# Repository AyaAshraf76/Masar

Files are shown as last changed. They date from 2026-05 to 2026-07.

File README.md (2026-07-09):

# Masar — Autonomous Self-Driving Car

Graduation project: a self-driving RC car with lane keeping, lane changing, adaptive cruise control (ACC), and self-parking. Built on a Raspberry Pi 5 + STM32 platform with LiDAR and camera, tested on a custom racetrack with two lanes and a parking area.

## Repo structure

| Folder | What's in it |
|---|---|
| `firmware/` | STM32 motor PID + encoder firmware |
| `trajectory_control/` | Kinematics, pure pursuit, trajectory controller (runs on Pi) |
| `perception/lane_detection/` | ONNX lane detection model + ROS2 lane_bridge + viewer |
| `adaptive_cruise_control/` | LiDAR streaming + ROS2 ACC nodes + motor server |
| `self_parking/` | ROS2 self-parking pipeline (camera, U-Net, YOLO, path planner) |
| `rl_lane_keeping/` | PPO training scripts for lane keeping in simulation (v3 → v3.3) |
| `simulation/` | Unity sim build + gym-donkeycar submodule |
| `car_design/` | Mechanical CAD + PCB files (to be added) |
| `dev_tools/` | Old motor test scripts, kept for reference |

## System overview

The car runs a Raspberry Pi 5 as the main computer and an STM32 for low-level motor control, connected over UART. ROS2 Humble runs on a laptop and handles the heavier processing (ACC, self-parking decisions). Sensor data goes from the Pi to the laptop over TCP, and speed commands come back the same way.

```
Raspberry Pi 5                         Laptop (ROS2)
───────────────                        ─────────────
lane_stream_final.py  ── TCP:9999 ──>  lane_bridge_node    -> /lane_error, /current_lane
                       └─ TCP:9998 ──>  lane_viewer.py

lidar_stream.py       ── TCP:9997 ──>  lidar_bridge_node   -> /scan
                                        acc_node            -> /acc_speed_command, /acc_zone
acc_motor_server.py   <── TCP:9998 ──  acc_tcp_sender_node

trajectory_angle_v11.py
  -> kinematics.py / pure_pursuit.py -> stm32_bridge_uart.py -- UART --> STM32 --> motors
```

## Hardware

- Raspberry Pi 5 — camera inference, trajectory control
- STM32 — motor PWM, encoder feedback, odometry
- Pi Camera — lane detection input (320×240 RGB → ONNX segmentation)
- RPLIDAR A1M8 — obstacle detection for ACC
- 4WD differential drive chassis, two lanes 35cm wide each

## Lane detection

3-class semantic segmentation (background / solid boundary / lane separator) running on the Pi at ~5 FPS. The model outputs pixel-level masks, post-processing extracts lane geometry (center, width, which lane, error in cm, curvature). Two calibration values per lane convert pixel error to real-world centimeters.

## Lane keeping + lane changing

The trajectory controller is a state machine:

- **LANE_KEEPING** — PID on `error_cm` from camera, with confidence-scaled low-pass, innovation clamp, leaky integral for corners, and corner slowdown
- **LANE_CHANGING** — pure pursuit following S-curve waypoints from current pose to adjacent lane
- **STOPPED** — motors off (ACC red zone or manual stop)

## ACC

LiDAR zones: GREEN (full speed), YELLOW (slow), RED (stop). The ACC node filters points to a forward cone, clusters them, and rejects wall-sized returns. Only brakes for obstacles in the car's own lane — if the other lane is clear, it can trigger a lane change instead.

## RL training (simulation)

PPO agent trained in DonkeyCar simulator. Key iterations:

- **v3** — switched to steering-rate actions (policy outputs a delta, not absolute angle) to fix bang-bang behavior. Made reward always ≥ 0 while alive so crashing is never better than staying on track
- **v3.2** — added damping bonus to penalize high lateral speed near the target. Added always-on speed term for the throttle head
- **v3.3** — widened damping window with glide-slope approach. Capped speed during lane changes to reduce entry oscillation

## Getting the code

```bash
git clone --recurse-submodules <repo-url>
# or if already cloned:
git submodule update --init --recursive
```

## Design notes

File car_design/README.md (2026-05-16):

# Car Design

Mechanical CAD and PCB design files for the car.

- `mechanical/` — chassis CAD files
- `pcb/` — PCB design files (KiCad)

Files to be added.

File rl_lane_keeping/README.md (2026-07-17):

# RL Lane Keeping

PPO lane-keeping agent trained in the DonkeyCar simulator (Unity). The car drives on a two-lane oval track (inner lane at CTE = -1.6, outer at CTE = +1.6, walls at ±3.2) and has to track a target that switches lanes every 1500 steps.

Went through six iterations (v1 → v3.3) to get from 30 crashes per 5000 steps to zero crashes with tight tracking.

## Development history

### v1 (baseline) — 500k steps
First attempt. 30 crashes in 5000 steps, all the same pattern: the car corrects with full steering lock, recovers, then holds full lock for 12-15 more steps and sweeps into the opposite wall. 72% of steps were at steering saturation (±1.00). Never reached the left lane at all.

Two problems: (1) no lateral velocity in the observation, so the policy couldn't tell "still drifting" from "already recovered", and (2) raw steering output clips to [-1,+1] which makes a Gaussian policy collapse into bang-bang control.

### v2 — added cte_rate to observation
Added per-step CTE change to the obs. Crashes continued — having the info helped but the bang-bang steering made it impossible to act on it. Necessary but not sufficient.

### v3 — structural fixes (the big one)
Two changes that fixed everything:

1. **Positive reward while alive**: the old reward made crashing rational — sitting in the wrong lane cost ~-2/step forever, crashing cost -5 once. The policy correctly learned to crash. Fix: reward is always ≥ 0 while alive, crash = -10. Now surviving always beats dying.

2. **Steering-rate actions**: instead of outputting a raw angle, the policy outputs a steering *delta* (max ±0.15/step), integrated by the wrapper. Sweeping across the track now takes many deliberate actions instead of one held saturation. Current steering angle added to obs.

Also fixed: cte_rate spike on first step (stale last_cte), cte_rate scaled ×5.

Result: **zero crashes** for the first time. Outer lane median error 0.22. But the inner lane had a ~200-step limit cycle (sweeping ±2.2 through the target), and the throttle head went dead.

### v3.1 — damping bonus
Added `r_damp`: bonus for arriving at the target slowly (low lateral velocity when close). Always-on speed term to wake up the throttle head.

Result: right lane improved to 0.10 median error. But 5 crashes appeared at one specific track location — car held full-left lock drifting into the wall for 14 steps. The damping only fired below error 0.5, and the near-wall reward was too weak to pull it back.

### v3.2 — wall drift arrest
Added a near-wall bonus (when CTE > 2.0) rewarding low lateral velocity regardless of lane error.

Result: **zero crashes** again. Max CTE dropped from 3.26 to 2.43. Left lane mean error down to 1.30, oscillation range contracted to [-2.3, +1.5]. But the limit cycle still survived at reduced amplitude.

### v3.3 — glide-slope damping + lane-change speed cap
Two targeted fixes:

1. Widened damping window to error < 0.9 with allowed lateral speed scaling with distance (allowed = 0.10 + 0.35 × lane_error). Rewards decelerating approach at every distance, not just the last 0.5.

2. Cut throttle to 0 during lane changes when speed > 0.45. The old code let the car enter the new lane at 0.8 speed with lateral rate ~1.2, seeding the oscillation every time.

## Results summary

Eval is a deterministic 5000-step rollout. "Right err" is the median tracking error on the outer lane (+1.6), "Left err" is the mean error on the inner lane (-1.6).

| Version | What changed | Crashes | Right err | Left err | Max CTE |
|---|---|---|---|---|---|
| v1 | baseline | 30 | — | — | >3.2 |
| v2 | + cte_rate obs | ~30 | — | — | >3.2 |
| v3 | rate actions + positive reward | 0 | 0.22 | 1.93 | 2.63 |
| v3.1 | + damping + speed term | 5 | 0.10 | 1.60 | 3.26 |
| v3.2 | + wall drift arrest | 0 | 0.09 | 1.30 | 2.43 |
| v3.3 | + glide-slope + entry cap | 0 | 0.09 | 1.17 | 2.37 |

The biggest jump was v3: replacing the reward (so crashing is never better than surviving) and switching to steering-rate actions (so bang-bang is impossible). Everything after that was reward tuning to tighten tracking.

## Files

- `train_lane_scratch_v3.py` — v3: steering-rate actions + positive reward
- `train_lane_scratch_v3_2.py` — v3.2: damping + always-on speed + wall drift arrest
- `train_lane_scratch_v3_3.py` — v3.3: glide-slope damping + lane-change speed cap
- `ppo_lane_scratch_v3.zip` — trained model weights (place in same dir to resume)
- `measure_cte.py` — logs CTE values while driving in the sim, for checking tracking accuracy

## Running

```bash
# train (resumes from ppo_lane_scratch_v3.zip if present)
python train_lane_scratch_v3_3.py

# measure CTE while manually driving
python measure_cte.py
```

Needs `gymnasium`, `gym_donkeycar`, `stable-baselines3`, `torch`, and the Unity sim binary from `simulation/`.

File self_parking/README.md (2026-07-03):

# Self-Parking

ROS2 node pipeline that lets the car detect a parking slot, decide
whether to enter it, and drive itself in — all on the same racetrack
used for lane keeping/ACC, in the dedicated parking-slot area.

These currently live as plain node scripts (not yet wrapped into a
colcon package like `lane_bridge` / `acc_controller`) — see the
**Packaging** note at the bottom.

## Pipeline / data flow

```
camera_receiver_node ──▶ /camera/image_raw ──┬──▶ unet_node ──▶ /lane_mask, /lane_class
                                              │         │
                                              │         ▼
                                              │   lane_analyzer_node ──▶ /lane_center, /lane_error,
                                              │                          /lane_width, /lane_heading,
                                              │                          /lane_confidence
                                              │
                                              └──▶ yolo_parking_node ──▶ /parking_slot_available,
                                                    parking_slot_node       /parking_slot_center_x/y,
                                                                            /parking_slot_width/height

/lane_error + parking-slot topics ──▶ decision_manager_node ──▶ /parking_state, /parking_target_x

/parking_state, /parking_target_x, /lane_error ──▶ path_planner_node ──▶ /target_steering,
                                                                          /target_speed,
                                                                          /parking_direction

/target_steering, /target_speed, /parking_direction ──▶ wheel_mixer_node ──▶ /wheel_rpm

/wheel_rpm ──▶ tcp_bridge_node ──▶ (TCP) ──▶ Raspberry Pi / STM32 motors
```

## Files

| File | Role |
|---|---|
| `camera_receiver_node.py` | Receives camera frames over TCP/socket and publishes `sensor_msgs/Image` on `/camera/image_raw`. |
| `unet_node.py` | Runs the U-Net segmentation model on each frame, publishes the lane mask and class. |
| `lane_analyzer_node.py` | Turns the segmentation mask into lane center, error, width, heading, and confidence. |
| `yolo_parking_node.py` | YOLO-based detection of the parking slot marker/box. |
| `parking_slot_node.py` | Turns the YOLO detection into slot availability + geometry (`center_x`, `center_y`, `width`, `height`). |
| `decision_manager_node.py` | State machine: decides when to leave lane-following and commit to a parking maneuver, publishes `/parking_state` and `/parking_target_x`. |
| `path_planner_node.py` | Converts the current decision state + lane/slot geometry into steering, speed, and parking-direction commands. |
| `wheel_mixer_node.py` | Mixes steering/speed/direction into individual `/wheel_rpm` targets for all four motors. |
| `tcp_bridge_node.py` | Sends the final `/wheel_rpm` targets over TCP to the Raspberry Pi / STM32 motor firmware. |

## Packaging

For consistency with `perception/lane_detection/ros2_ws` and
`adaptive_cruise_control/ros2_ws`, these nine nodes should eventually
be wrapped into one or two proper `ament_python` ROS2 packages (e.g.
`self_parking_perception` for the camera/U-Net/YOLO/lane-analyzer
nodes and `self_parking_control` for decision-manager/path-planner/
wheel-mixer/tcp-bridge) with their own `package.xml` / `setup.py`. Left
as-is for now since that wasn't part of the requested reorganization —
happy to do that pass next if useful.

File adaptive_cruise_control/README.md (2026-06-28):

# Adaptive Cruise Control (LiDAR)

LiDAR-based ACC system. The Pi streams LiDAR scans to the laptop, ROS2 nodes process them into speed decisions, and the result is sent back to control the motors.

## Files

- `lidar_stream.py` — runs on Pi, reads RPLIDAR A1M8 and streams scans over TCP (port 9997)
- `acc_motor_server.py` — runs on Pi, receives speed commands from laptop via TCP and sends RPM targets to STM32 over UART
- `acc_tcp_sender_node.py` — ROS2 node on laptop, forwards `/acc_speed_command` to the Pi over TCP
- `ros2_ws/src/lidar_bridge/` — ROS2 node that converts the TCP scan stream to `/scan` topic
- `ros2_ws/src/acc_controller/` — ROS2 node that processes `/scan` into speed zones (GREEN/YELLOW/RED)

## How it works

The ACC node filters LiDAR points to a forward cone, clusters them, and keeps only car-sized clusters (rejects the track wall). It uses lane-aware lateral gates so the wall is never mistaken for a car. Publishes `/acc_speed_command` and `/acc_zone`.

## Running

```bash
# Pi terminal 1: LiDAR stream
source ~/lane_env/bin/activate
python3 lidar_stream.py

# Pi terminal 2: motor server (receives speed from laptop, sends to STM32)
python3 acc_motor_server.py

# Laptop terminal 1 — LiDAR bridge:
source /opt/ros/humble/setup.bash && source ~/ros2_ws/install/setup.bash
export ROS_DOMAIN_ID=42
ros2 run lidar_bridge lidar_bridge_node

# Laptop terminal 2 — ACC controller:
source /opt/ros/humble/setup.bash && source ~/ros2_ws/install/setup.bash
export ROS_DOMAIN_ID=42
ros2 run acc_controller acc_node

# Laptop terminal 3 — send speed back to Pi:
source /opt/ros/humble/setup.bash && source ~/ros2_ws/install/setup.bash
export ROS_DOMAIN_ID=42
ros2 run acc_tcp_sender acc_tcp_sender_node

# Monitor:
ros2 topic echo /acc_zone
ros2 topic echo /acc_speed_command
```

For quick tests without building ROS2 packages, `acc_node.py` can run as a standalone script — just source the ROS2 setup so `rclpy` is on the path.

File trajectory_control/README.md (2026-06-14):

# Trajectory Control

High-level trajectory controller running on the Raspberry Pi. Reads lane detection data and ACC commands, computes motor speeds using PID lane keeping or pure pursuit lane changing, and sends them to the STM32 over UART.

## Files

- `trajectory_angle_v11.py` — main controller (state machine: LANE_KEEPING / LANE_CHANGING / STOPPED)
- `kinematics.py` — differential drive forward/inverse kinematics
- `pure_pursuit.py` — pure pursuit path follower for lane changes
- `stm32_bridge_uart.py` — UART interface to the STM32 (send targets, read odometry)

## Running

```bash
python3 trajectory_angle_v11.py
```

Connects to lane_stream_final.py on port 9999 and to the STM32 on `/dev/ttyAMA0`.

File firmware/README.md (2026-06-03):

# STM32 Firmware

PID motor control firmware for the STM32. Handles encoder reading, PID speed control for all 4 wheels, and UART communication with the Raspberry Pi.

## Communication protocol

Receives: `TARGET,rpm1,rpm2,rpm3,rpm4\n`
Sends back: `ODOM,x,y,theta,rpm1,rpm2,rpm3,rpm4\n`

Watchdog timeout: if no TARGET command received for ~200ms, motors stop automatically.

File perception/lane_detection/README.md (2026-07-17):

# Lane Detection and Lane Keeping Perception

Camera-based lane perception for the **MASAR autonomous vehicle**, running on a Raspberry Pi 5 with a Raspberry Pi Camera Module V3.

The subsystem uses a **MobileNetV2-U-Net semantic-segmentation model** exported to ONNX to detect the track markings, estimate the active lane and lane center, calculate lateral error, assign a confidence value, and stream the results to the ROS 2 control stack.

> This module is responsible for perception only. It does not command the motors directly. The trajectory controller consumes its lane measurements and generates the vehicle motion commands.

## System Overview

```mermaid
flowchart LR
    A[Pi Camera V3<br/>640 x 480] --> B[Preprocessing<br/>RGB, resize, normalize]
    B --> C[MobileNetV2-U-Net<br/>ONNX Runtime on Pi 5]
    C --> D[3-Class<br/>Segmentation Mask]
    D --> E[Lane Geometry<br/>Center, width, lane ID, error]
    E --> F[JSON Stream<br/>TCP 9999]
    E --> G[Annotated JPEG Stream<br/>TCP 9998]
    F --> H[ROS 2 lane_bridge]
    H --> I[Lane-Keeping / Trajectory Controller]
    G --> J[Laptop Viewer]
```

### End-to-End Processing Sequence

1. Capture a `640 x 480` frame using Pi Camera V3.
2. Convert the frame to RGB.
3. Resize it to the model input size, `320 x 240`.
4. Normalize pixel values to `[0, 1]` and convert from HWC to CHW format.
5. Run one ONNX inference pass.
6. Apply `argmax` across the model classes to obtain a class-index mask.
7. Process the bottom 80% of the mask as the region of interest.
8. Extract solid-boundary and lane-separator pixels.
9. Estimate the active lane, lane width, and lane center.
10. Calculate signed error in pixels and an approximate lane-aware error in centimeters.
11. Assign a confidence value based on the available visual evidence.
12. Send lane data to the ROS 2 bridge and stream an annotated frame to the viewer.

## Model

### Architecture

- **Task:** Semantic segmentation
- **Encoder:** MobileNetV2 with transfer learning
- **Decoder:** U-Net-style upsampling path
- **Deployment format:** ONNX
- **Runtime:** ONNX Runtime on Raspberry Pi 5 CPU
- **Input:** `1 x 3 x 240 x 320` RGB tensor
- **Output:** Per-class score map converted to a mask using `argmax`

MobileNetV2-U-Net was selected as a practical compromise between pixel-level segmentation quality and the computational limits of real-time Raspberry Pi deployment.

### Segmentation Classes

| Class ID | Class | Meaning |
|---:|---|---|
| `0` | Background | All pixels that are not lane markings |
| `1` | Solid boundary | Solid white track boundary |
| `2` | Lane separator | Dashed separator between the inner and outer lanes |

### Custom Dataset

A project-specific dataset was collected because public road datasets do not match the indoor RC-car environment. The final dataset includes:

- Inner- and outer-lane views
- Straight sections and curves
- Centered and laterally shifted vehicle positions
- Partial line visibility
- Imperfect driving cases
- The real camera mounting height, tilt, lighting, reflections, and track geometry

Images were labeled with **LabelMe** and converted from annotation JSON files into class-index masks for training.

## Lane Geometry and Error Calculation

### Region of Interest

The geometry stage uses the bottom 80% of the predicted mask:

```text
roi_top = int(0.20 * image_height)
ROI = mask[roi_top:image_height, 0:image_width]
```

The upper part of the image contains distant markings that are more affected by perspective and contribute less reliable information for immediate vehicle control.

### Lane Center

When both markings are valid, the lane center is the midpoint between the solid boundary and separator:

```text
lane_center_x = (solid_x + separator_x) / 2
```

When only one marking is visible, the center is reconstructed using lane-aware geometry, remembered lane width, or the learned offset associated with the cleaner visible line.

### Error Convention

```text
image_center_x = image_width / 2
error_px = lane_center_x - image_center_x
```

- `error_px > 0`: the estimated lane center is to the right of the image center.
- `error_px < 0`: the estimated lane center is to the left of the image center.

The pixel error is the primary perception measurement passed to the controller.

### Pixel-to-Centimeter Calibration

The centimeter value is an auxiliary, lane-aware estimate:

```text
error_calibrated_px = error_px - lane_offset_px
error_cm = error_calibrated_px / pixels_per_cm
```

Documented calibration values:

| Constant | Value |
|---|---:|
| Physical lane width | `36.7 cm` |
| Outer-lane zero offset | `-8.5 px` |
| Inner-lane zero offset | `-7.5 px` |
| Outer-lane scale | `2.19 px/cm` |
| Inner-lane scale | `2.51 px/cm` |

The centimeter estimate is most reliable on straight sections. In curves, perspective and vehicle-heading error affect the image measurement, so `error_cm` should be treated as approximate.

## Confidence Logic

| Visual evidence | Estimation method | Confidence |
|---|---|---:|
| Solid boundary and separator visible | Midpoint of both markings | `1.0` |
| Solid boundary only | Single-line reconstruction | `0.5` |
| Separator only | Single-line reconstruction | `0.4` |
| No marking, previous center available | Low-confidence fallback | `0.2` |
| No usable estimate | Image-center fallback | `0.0` |

Confidence allows the controller to reduce trust in ambiguous measurements instead of treating every frame as equally reliable.

## Output Data

The lane stream sends JSON data through TCP port `9999`. The exact payload can evolve with the runtime script, but the principal fields are:

| Field | Description |
|---|---|
| `lane` | Current lane: `inner`, `outer`, or `unknown` |
| `center` | Estimated lane center in model-image coordinates |
| `error` | Signed lateral error in pixels |
| `error_cm` | Approximate calibrated lateral error in centimeters |
| `confidence` | Reliability of the current estimate |
| `width` | Remembered lane width in pixels |
| `curvature` | Diagnostic separator-slope/curvature estimate |
| `solid_count` / `sep_count` | Number of detected pixels for each lane class |
| `solid_x` / `sep_x` | Representative positions of the detected markings |

The ROS 2 bridge converts the TCP data into lane topics used by the trajectory controller. Confirm the final topic names from `ros2_ws/src/lane_bridge/`.

## Runtime Communication

| Port | Data | Consumer |
|---:|---|---|
| `9999` | JSON lane geometry and diagnostics | ROS 2 bridge / trajectory controller |
| `9998` | Annotated JPEG frames | Laptop viewer |

Only one model inference is performed per camera frame. The same inference result is reused for the JSON output and visual stream to reduce Raspberry Pi CPU load.

## Files

- `lane_model.onnx` and `lane_model_onnx.data` - trained three-class segmentation model
- `lane_stream_final.py` - Pi camera capture, ONNX inference, geometry extraction, JSON server, and annotated-video server
- `lane_viewer.py` - laptop viewer for the annotated JPEG stream (`Q` to quit, `F` for fullscreen)
- `ros2_ws/src/lane_bridge/` - ROS 2 bridge from the Pi JSON stream to lane topics
- `Lane_Detection_Lane_Keeping_Chapter__3_.docx` - complete lane-detection and lane-keeping documentation
- `Lane_Detection_Challenges_Report.docx` - development challenges, diagnoses, and mitigation history

## Engineering Challenges and Final Mitigations

The largest errors occurred in curves, where perspective distortion, partial visibility, and segmentation ambiguity affected the geometric post-processing.

| Challenge | Root cause | Mitigation |
|---|---|---|
| Wrong solid-only fallback direction | The same `-lane_width/2` sign was used for both lanes | Use lane-aware signs for inner and outer lanes |
| Corner bias from full-ROI averaging | Far-ahead curved pixels shifted the arithmetic mean | Use a near-car median from the lowest valid rows |
| Two-wall contamination | Both solid walls could be classified as one class when the separator disappeared | Select the cluster nearest the previous trusted anchor |
| Large separator blob in the inner lane | The curved separator could be over-segmented into a wide region | Learn line-to-center offsets from clean frames and prefer the cleaner line |
| Polynomial-fit overshoot | A straight fit extrapolated below the available curved pixels | Avoid extrapolation; estimate only from observed near-car pixels |
| Anchor snowballing | A bad frame could corrupt the next frame's filter anchor | Save anchors before update and hard-update only from clean frames |
| Frozen output during contaminated frames | Holding the last clean result made the measurement unresponsive | Keep a live output and limit only the maximum per-frame jump |

These measures reduced isolated spikes and improved robustness, but they did not completely eliminate systematic curve error.

## Known Limitations

- Curves remain less accurate than straight sections because the separator may become a wide curved blob or leave the field of view.
- The system relies on one forward-facing camera, so single-line fallback is sometimes unavoidable.
- The observed processing rate is approximately `5-6 FPS`; at vehicle speed, this introduces measurable perception delay.
- The camera position and tilt must remain fixed after training and calibration.
- Strong glare and reflections from the indoor track can affect segmentation.
- The trained model is specialized for the project track and lighting distribution.
- The centimeter error is an approximate interpretation, not a complete ground-plane localization estimate.

## Future Improvements

- Add inverse perspective mapping / bird's-eye-view calibration.
- Apply camera undistortion using measured camera calibration parameters.
- Retrain with additional inner-lane corner, glare, blur, and partial-visibility examples.
- Replace single-position extraction with row-wise or polynomial lane modeling that does not extrapolate beyond observed pixels.
- Fuse camera measurements with wheel odometry or IMU data using a state estimator such as an Extended Kalman Filter.
- Increase inference frame rate through model optimization or hardware acceleration.
- Add physical-plausibility checks for impossible changes in lane width or error.

## Deploying the Model to the Raspberry Pi

Replace `<PI_IP>` with the current Raspberry Pi address.

```bash
scp lane_model.onnx pi@<PI_IP>:/home/pi/
scp lane_model_onnx.data pi@<PI_IP>:/home/pi/
```

Install the required runtime packages inside the environment used by the lane script:

```bash
pip install --upgrade onnxruntime numpy
```

### Verify That the Model Loads

```bash
python3 - <<'PY'
import numpy as np
import onnxruntime as ort

session = ort.InferenceSession(
    "/home/pi/lane_model.onnx",
    providers=["CPUExecutionProvider"],
)
input_name = session.get_inputs()[0].name
dummy = np.random.rand(1, 3, 240, 320).astype(np.float32)
output = session.run(None, {input_name: dummy})
print("Output shape:", output[0].shape)
print("Model loaded successfully")
PY
```

### Benchmark Inference

```bash
python3 - <<'PY'
import time
import numpy as np
import onnxruntime as ort

session = ort.InferenceSession(
    "/home/pi/lane_model.onnx",
    providers=["CPUExecutionProvider"],
)
input_name = session.get_inputs()[0].name
dummy = np.random.rand(1, 3, 240, 320).astype(np.float32)

for _ in range(5):
    session.run(None, {input_name: dummy})

samples = []
for _ in range(30):
    start = time.perf_counter()
    session.run(None, {input_name: dummy})
    samples.append(time.perf_counter() - start)

mean_time = float(np.mean(samples))
print(f"Mean inference: {mean_time * 1000:.1f} ms")
print(f"Inference FPS: {1.0 / mean_time:.1f}")
PY
```

## Running the Subsystem

### Raspberry Pi

```bash
source ~/lane_env/bin/activate
python3 lane_stream_final.py
```

### Laptop Viewer

```bash
python3 lane_viewer.py
```

### ROS 2 Bridge

```bash
source /opt/ros/humble/setup.bash
source ~/ros2_ws/install/setup.bash
ros2 run lane_bridge lane_bridge_node
```

## Documentation

For the full training methodology, equations, calibration, validation, curve analysis, and development history, see:

- `Lane_Detection_Lane_Keeping_Chapter__3_.docx`
- `Lane_Detection_Challenges_Report.docx`

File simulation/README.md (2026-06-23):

# Simulation

Unity-based simulation environment for training and testing.

- `unity_build/` — built simulator binary (worked_version.x86_64)
- `gym-donkeycar/` — OpenAI Gym wrapper (git submodule)

The RL training scripts in `rl_lane_keeping/` connect to this simulator.

```bash
# make sure submodule is initialized
git submodule update --init --recursive
```

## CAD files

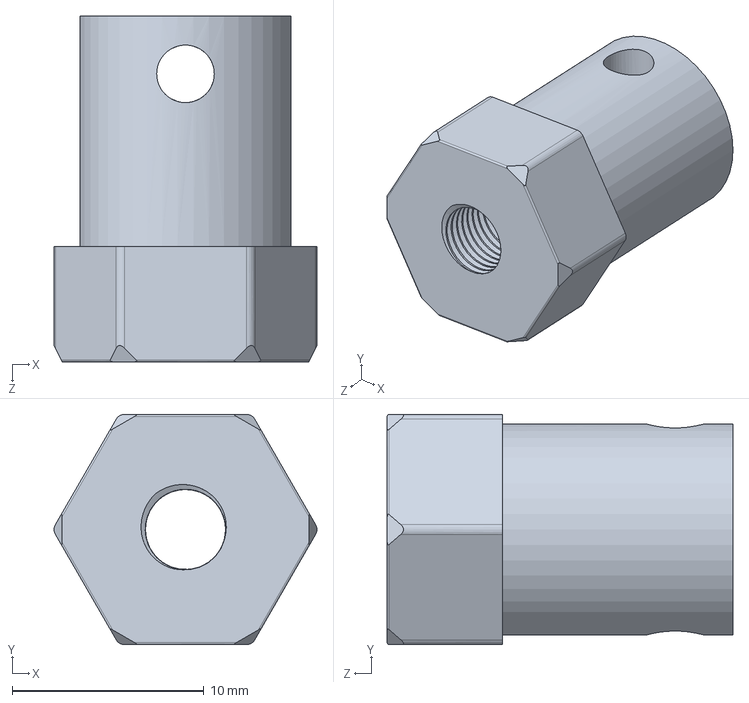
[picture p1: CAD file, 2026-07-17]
car_design/mechanical/motor_adapter.SLDPRT
13.7 x 12.0 x 18.0 mm

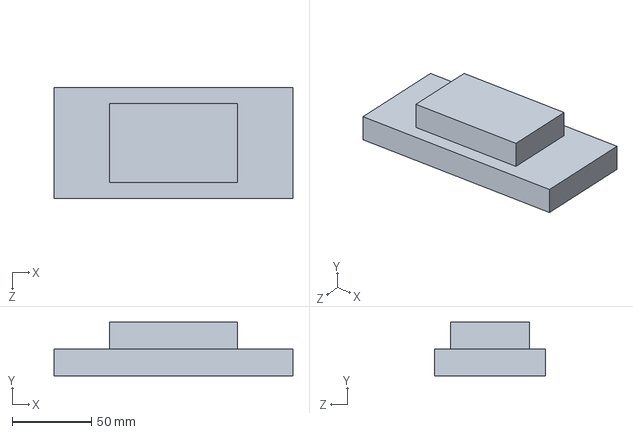
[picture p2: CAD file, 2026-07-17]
car_design/mechanical/POWERBANK.SLDPRT
151.0 x 34.0 x 70.0 mm

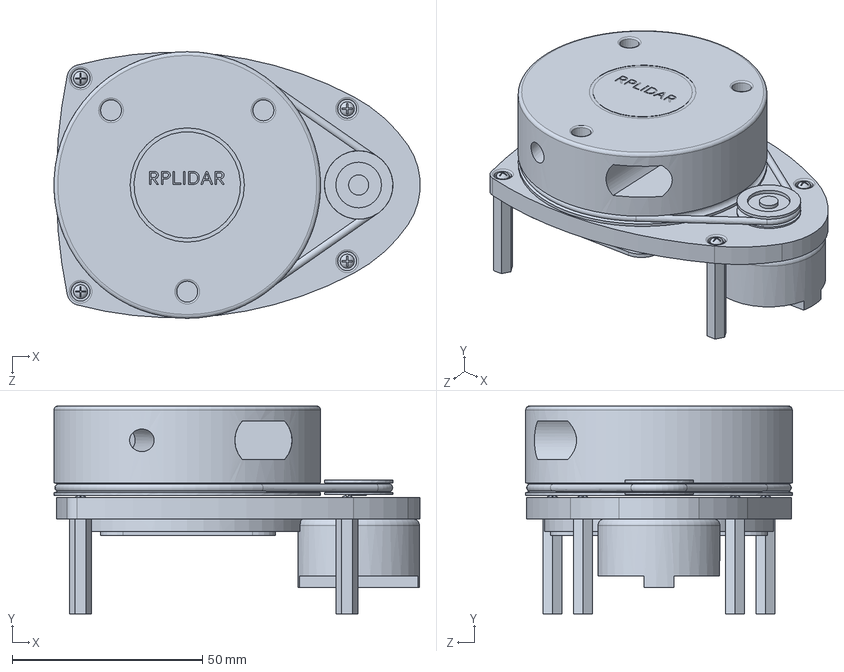
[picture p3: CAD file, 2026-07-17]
car_design/mechanical/RPLidar_SCTL.SLDPRT
96.1 x 54.6 x 70.0 mm

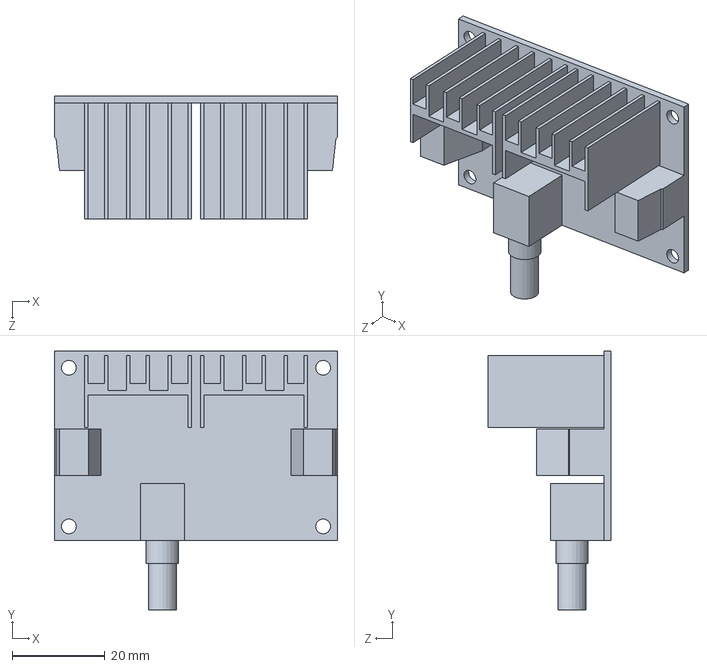
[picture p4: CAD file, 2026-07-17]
car_design/mechanical/xl4016.SLDPRT
61.0 x 55.8 x 26.6 mm

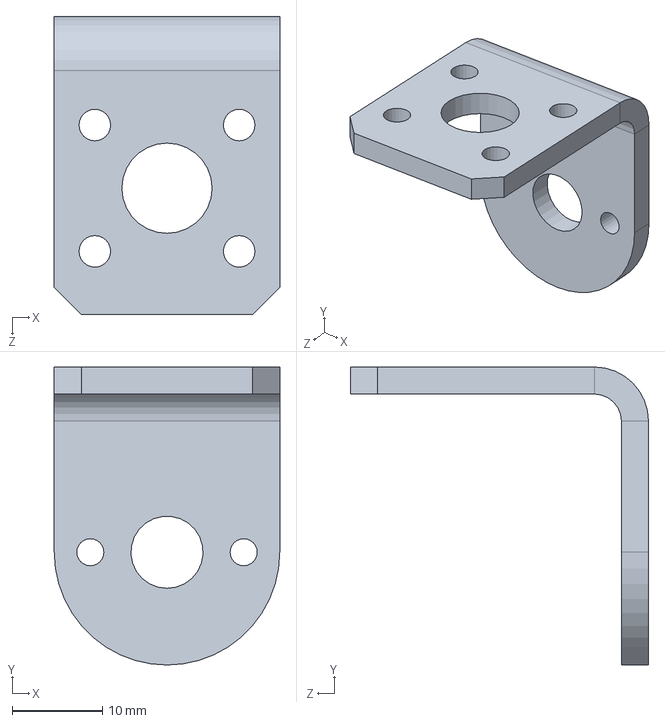
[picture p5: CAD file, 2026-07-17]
car_design/mechanical/DC motor Mount.SLDPRT
25.0 x 33.0 x 33.0 mm

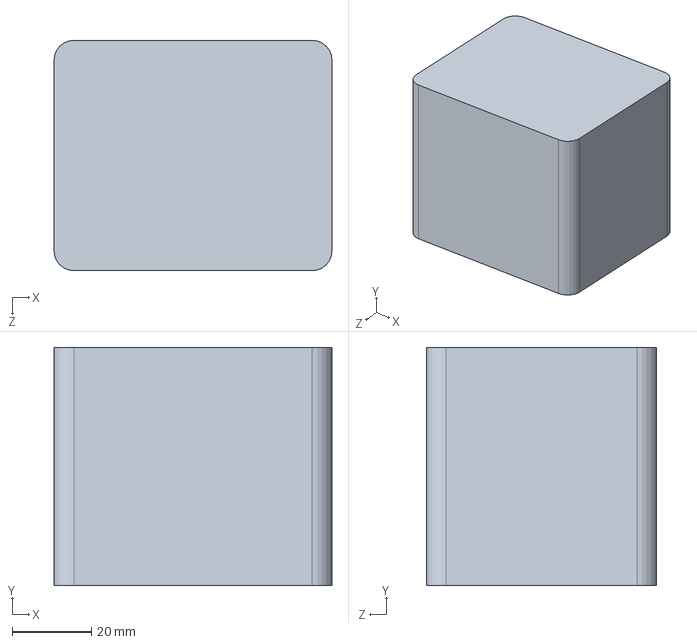
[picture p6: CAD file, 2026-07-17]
car_design/mechanical/battery.SLDPRT
70.0 x 60.0 x 58.0 mm

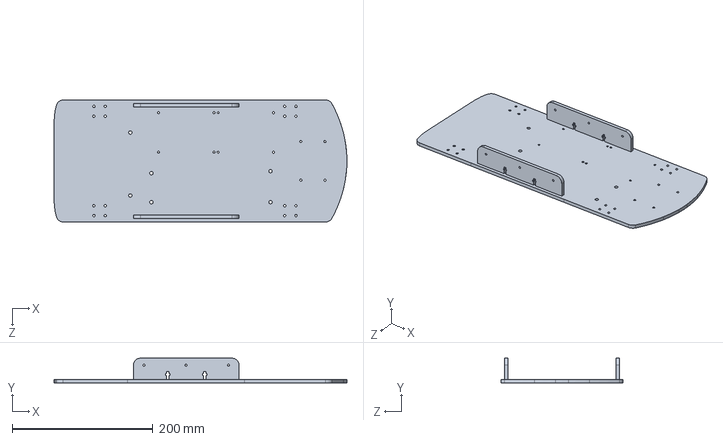
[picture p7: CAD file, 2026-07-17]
car_design/mechanical/chasiss.SLDPRT
415.6 x 35.0 x 173.0 mm

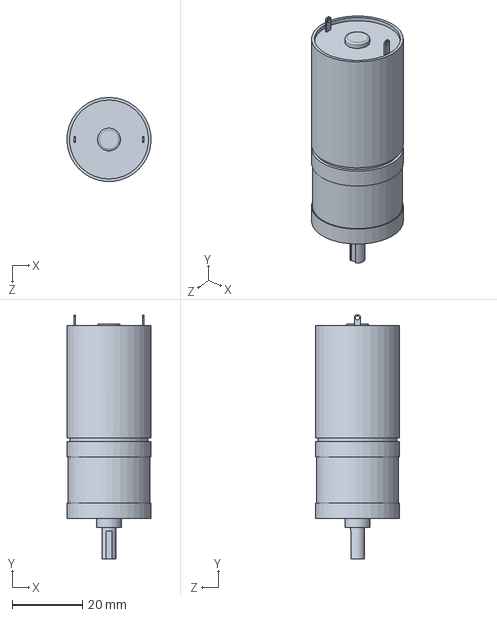
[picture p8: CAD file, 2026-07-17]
car_design/mechanical/DC-Motor.SLDPRT
24.0 x 69.5 x 24.0 mm

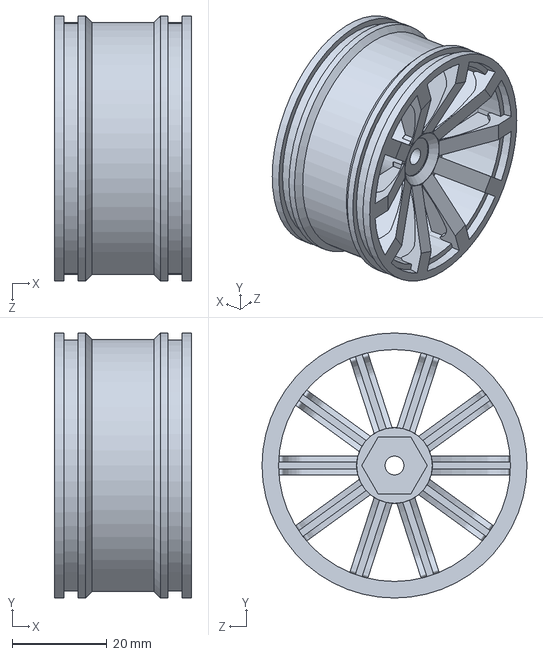
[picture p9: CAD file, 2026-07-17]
car_design/mechanical/blue_wheel_frame.SLDPRT
29.0 x 56.0 x 56.0 mm

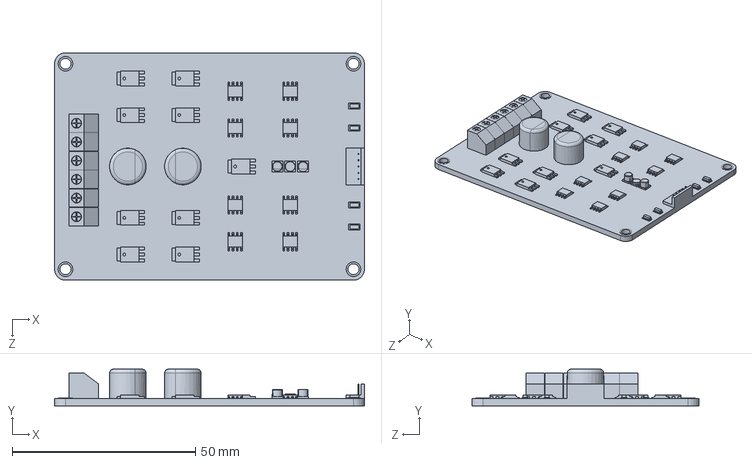
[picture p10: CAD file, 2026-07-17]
car_design/mechanical/Motor Driver.SLDPRT
84.5 x 10.0 x 62.0 mm

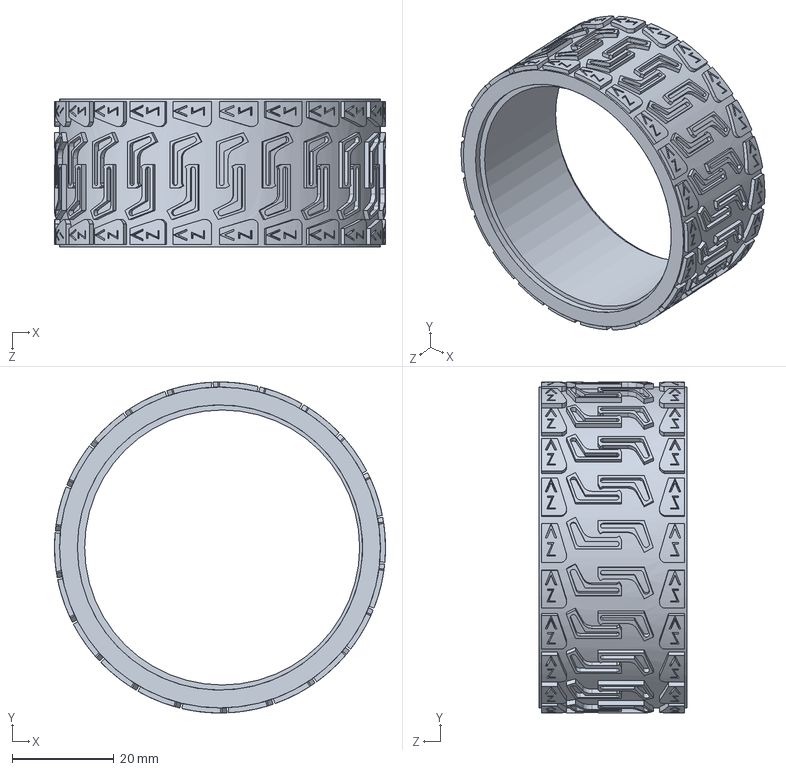
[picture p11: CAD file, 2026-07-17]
car_design/mechanical/65mm tire.SLDPRT
65.0 x 65.0 x 29.0 mm

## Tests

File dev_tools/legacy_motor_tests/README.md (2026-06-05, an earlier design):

# Legacy Motor Test Scripts

Early prototype firmware/scripts used while bringing up the drivetrain,
**before** the final PID+odometry firmware. Superseded by
`firmware/stm32_pid_uart/pid_realtime_uart.ino` +
`trajectory_control/stm32_bridge_uart.py`. Kept here for history only
— pin mappings in these files do **not** match the final control PCB.

| Folder | Purpose |
|---|---|
| `modes_feedback_motors/` | STM32 firmware (`modes_feedback_motors.ino`) + Pi-side script (`modes_pi.py`) for an interactive mode-select UART test: 4-wheel speed control vs. steering+speed control, with encoder feedback. Different pin mapping than the final firmware. |
| `motors_keyboard/` | Earliest open-loop test: STM32 firmware (`motors_keyboard.ino`, PWM/DIR only, no encoders/PID) driven from the Pi by raw keyboard input (`keyboard_motor.py`). |

If you don't need this history for the thesis appendix, this whole
folder can be deleted without affecting anything else in the repo.

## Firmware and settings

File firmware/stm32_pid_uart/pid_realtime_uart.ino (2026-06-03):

//////////////////// MOTOR 1 ////////////////////
#define ENCA1 PB3
#define ENCB1 PA15
#define PWM1  PA3
#define DIR1  PA2

//////////////////// MOTOR 2 ////////////////////
#define ENCA2 PB10
#define ENCB2 PB11
#define PWM2  PA1
#define DIR2  PA0

//////////////////// MOTOR 3 ////////////////////
#define ENCA3 PA4
#define ENCB3 PA5
#define PWM3  PA10
#define DIR3  PA9

//////////////////// MOTOR 4 ////////////////////
#define ENCA4 PB8
#define ENCB4 PB9
#define PWM4  PA8
#define DIR4  PB15

//////////////////////////////////////////////////
// UART2 to Raspberry Pi (PB6=TX, PB7=RX)
// Serial  = USB debug to laptop
// Serial2 = UART to Pi
//////////////////////////////////////////////////
HardwareSerial Serial2(PB7, PB6);

volatile long posi1=0, posi2=0, posi3=0, posi4=0;
volatile int  lastEncoded1=0, lastEncoded2=0;
volatile int  lastEncoded3=0, lastEncoded4=0;

float eintegral1=0, eintegral2=0, eintegral3=0, eintegral4=0;

float PPR          = 1980;
float WHEEL_RADIUS = 0.03367;  // update after calibration
float TRACK_WIDTH  = 0.74761;    // update after calibration

float target1=0, target2=0, target3=0, target4=0;

float kp1=4.0, ki1=0.5, kff1=2.4;
float kp2=4.0, ki2=0.5, kff2=2.4;
float kp3=4.0, ki3=0.5, kff3=2.4;
float kp4=4.0, ki4=0.5, kff4=2.4;
const float ICLAMP = 40.0;

// Odometry
float odom_x=0, odom_y=0, odom_theta=0;
long prevOdom1=0, prevOdom2=0, prevOdom3=0, prevOdom4=0;

// Watchdog: stop motors if Pi goes silent
unsigned long lastTargetMs = 0;
const unsigned long TIMEOUT_MS = 500;
bool rtActive = false;

// RPM state
static float _rpm1=0, _rpm2=0, _rpm3=0, _rpm4=0;
static long  _prevP1=0, _prevP2=0, _prevP3=0, _prevP4=0;

void setup() {
  Serial.begin(115200);    // USB debug -- connect to laptop to monitor
  Serial2.begin(115200);   // UART to Pi on PB6/PB7

  pinMode(ENCA1,INPUT_PULLUP); pinMode(ENCB1,INPUT_PULLUP);
  pinMode(ENCA2,INPUT_PULLUP); pinMode(ENCB2,INPUT_PULLUP);
  pinMode(ENCA3,INPUT_PULLUP); pinMode(ENCB3,INPUT_PULLUP);
  pinMode(ENCA4,INPUT_PULLUP); pinMode(ENCB4,INPUT_PULLUP);

  attachInterrupt(digitalPinToInterrupt(ENCA1),readEncoder1,CHANGE);
  attachInterrupt(digitalPinToInterrupt(ENCB1),readEncoder1,CHANGE);
  attachInterrupt(digitalPinToInterrupt(ENCA2),readEncoder2,CHANGE);
  attachInterrupt(digitalPinToInterrupt(ENCB2),readEncoder2,CHANGE);
  attachInterrupt(digitalPinToInterrupt(ENCA3),readEncoder3,CHANGE);
  attachInterrupt(digitalPinToInterrupt(ENCB3),readEncoder3,CHANGE);
  attachInterrupt(digitalPinToInterrupt(ENCA4),readEncoder4,CHANGE);
  attachInterrupt(digitalPinToInterrupt(ENCB4),readEncoder4,CHANGE);

  pinMode(PWM1,OUTPUT); pinMode(DIR1,OUTPUT);
  pinMode(PWM2,OUTPUT); pinMode(DIR2,OUTPUT);
  pinMode(PWM3,OUTPUT); pinMode(DIR3,OUTPUT);
  pinMode(PWM4,OUTPUT); pinMode(DIR4,OUTPUT);

  Serial.println("READY - debug on USB, Pi on Serial2 PB6/PB7");
  Serial2.println("READY");
}

void loop() {
  // Read commands from Pi on Serial2
  static char buf[64];
  static uint8_t blen = 0;

  while (Serial2.available()) {
    char c = Serial2.read();
    if (c == '\n') {
      buf[blen] = '\0';
      if (strncmp(buf, "TARGET,", 7) == 0) {
        parseTarget(buf);
      } else if (blen == 1 && buf[0] == 'r') {
        resetOdom();
      }
      blen = 0;
    } else if (c != '\r' && blen < 63) {
      buf[blen++] = c;
    }
  }

  static unsigned long lastTime = 0;
  if (millis() - lastTime < 20) return;
  lastTime = millis();
  float dt = 0.02;

  // Watchdog: Pi went silent -> stop motors
  if (rtActive && (millis() - lastTargetMs) > TIMEOUT_MS) {
    target1=target2=target3=target4=0;
    eintegral1=eintegral2=eintegral3=eintegral4=0;
    rtActive = false;
    Serial.println("WATCHDOG: Pi silent, motors stopped");
  }

  // Odometry update
  long s1,s2,s3,s4;
  noInterrupts(); s1=posi1;s2=posi2;s3=posi3;s4=posi4; interrupts();
  float tpm = PPR / (2.0*PI*WHEEL_RADIUS);
  // Physical test confirmed: M2/M3 are the RIGHT side, M1/M4 are the LEFT side
  // despite their pin names -- swap dL/dR accordingly
  float dL = ((s1-prevOdom1 + s4-prevOdom4)/2.0) / tpm;  // M1,M4 = physical LEFT
  float dR = ((s2-prevOdom2 + s3-prevOdom3)/2.0) / tpm;  // M2,M3 = physical RIGHT
  prevOdom1=s1; prevOdom2=s2; prevOdom3=s3; prevOdom4=s4;
  float dc   = (dL+dR)/2.0;
  // Negated: physically turning right increases theta in our setup
  float dth  = -((dR-dL)/TRACK_WIDTH);
  float tmid = odom_theta + dth/2.0;
  odom_x     += dc*cos(tmid);
  odom_y     += dc*sin(tmid);
  odom_theta += dth;
  odom_theta  = atan2(sin(odom_theta),cos(odom_theta));

  // PID
  runPID(dt);

  // Send odometry to Pi on Serial2
  // Format: ODOM,x,y,theta,rpm1,rpm2,rpm3,rpm4
  Serial2.print(F("ODOM,"));
  Serial2.print(odom_x,4);    Serial2.print(',');
  Serial2.print(odom_y,4);    Serial2.print(',');
  Serial2.print(odom_theta,5);Serial2.print(',');
  Serial2.print(_rpm1,2);     Serial2.print(',');
  Serial2.print(_rpm2,2);     Serial2.print(',');
  Serial2.print(_rpm3,2);     Serial2.print(',');
  Serial2.println(_rpm4,2);

  // Mirror odometry to USB debug port so you can monitor on laptop too
  Serial.print(F("ODOM,"));
  Serial.print(odom_x,4);    Serial.print(',');
  Serial.print(odom_y,4);    Serial.print(',');
  Serial.print(odom_theta*180.0/PI,2); Serial.print(F("deg | RPM "));
  Serial.print(_rpm1,1); Serial.print(' ');
  Serial.print(_rpm2,1); Serial.print(' ');
  Serial.print(_rpm3,1); Serial.print(' ');
  Serial.println(_rpm4,1);
}

void parseTarget(char* line) {
  char tmp[64]; strncpy(tmp,line,63); tmp[63]='\0';
  strtok(tmp,",");
  char* t1=strtok(NULL,","); if(!t1) return;
  char* t2=strtok(NULL,","); if(!t2) return;
  char* t3=strtok(NULL,","); if(!t3) return;
  char* t4=strtok(NULL,","); if(!t4) return;
  target1=atof(t1); target2=atof(t2);
  target3=atof(t3); target4=atof(t4);
  lastTargetMs=millis();
  rtActive=true;
}

void resetOdom() {
  odom_x=odom_y=odom_theta=0;
  noInterrupts();
  prevOdom1=posi1; prevOdom2=posi2;
  prevOdom3=posi3; prevOdom4=posi4;
  interrupts();
  Serial2.println(F("ODOM RESET"));
  Serial.println(F("Odometry reset"));
}

void runPID(float dt) {
  auto calcRPM = [&](volatile long& posi, long& prev, float& filt) {
    long snap; noInterrupts(); snap=posi; interrupts();
    float raw = ((snap-prev)/PPR)*(60.0/dt);
    prev = snap;
    filt = 0.8*filt + 0.2*raw;
  };
  calcRPM(posi1,_prevP1,_rpm1);
  calcRPM(posi2,_prevP2,_rpm2);
  calcRPM(posi3,_prevP3,_rpm3);
  calcRPM(posi4,_prevP4,_rpm4);

  auto pidStep = [&](float tgt, float rpm, float& eint,
                     float kp, float ki, float kff,
                     int pwm, int dir) {
    float u = kff*tgt + kp*(tgt-rpm) + ki*eint;
    float pwr = fabs(u); if(pwr>255) pwr=255;
    if(fabs(tgt-rpm)>15) pwr=max(pwr,150.0f);
    setMotor(pwm, dir, (u>=0)?1:-1, pwr);
    if(pwr<255){ eint+=(tgt-rpm)*dt; eint=constrain(eint,-ICLAMP,ICLAMP); }
  };

  pidStep(target1,_rpm1,eintegral1,kp1,ki1,kff1,PWM1,DIR1);
  pidStep(target2,_rpm2,eintegral2,kp2,ki2,kff2,PWM2,DIR2);
  pidStep(target3,_rpm3,eintegral3,kp3,ki3,kff3,PWM3,DIR3);
  pidStep(target4,_rpm4,eintegral4,kp4,ki4,kff4,PWM4,DIR4);
}

void setMotor(int pwmPin, int dirPin, int dir, float pwmVal) {
  analogWrite(pwmPin, (int)pwmVal);
  digitalWrite(dirPin, dir==1 ? HIGH : LOW);
}

#define ENC_ISR(N,A,B,pos,last) \
void readEncoder##N() { \
  int e=(digitalRead(A)<<1)|digitalRead(B); \
  int s=(last<<2)|e; \
  if(s==0b1101||s==0b0100||s==0b0010||s==0b1011) pos++; \
  if(s==0b1110||s==0b0111||s==0b0001||s==0b1000) pos--; \
  last=e; \
}

ENC_ISR(1,ENCA1,ENCB1,posi1,lastEncoded1)
ENC_ISR(2,ENCA2,ENCB2,posi2,lastEncoded2)
ENC_ISR(3,ENCA3,ENCB3,posi3,lastEncoded3)
ENC_ISR(4,ENCA4,ENCB4,posi4,lastEncoded4)

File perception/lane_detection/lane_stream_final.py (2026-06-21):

#!/usr/bin/env python3
"""
Lane Detection - Combined Final Script
Runs on Raspberry Pi 5

Does TWO things simultaneously from ONE inference:
  1. Sends JSON data  ^f^r port 9999  ^f^r ROS2 bridge on laptop
  2. Sends visual stream  ^f^r port 9998  ^f^r viewer on laptop

error_cm is a pure post-calculation added on top of the
existing lane-aware pixel error. Lane detection logic,
ROI, voting, and smoothing are UNCHANGED.

Both lanes are 35cm wide in reality (confirmed).
"""

import cv2
import numpy as np
import onnxruntime as ort
import socket
import struct
import time
import json
import threading
from picamera2 import Picamera2
from libcamera import controls
from collections import deque, Counter


#  ^t^` ^t^` Configuration  ^t^` ^t^` ^t^` ^t^` ^t^` ^t^` ^t^` ^t^` ^t^` ^t^` ^t^` ^t^` ^t^` ^t^` ^t^` ^t^` ^t^` ^t^` ^t^` ^t^` ^t^` ^t^` ^t^` ^t^` ^t^` ^t^` ^t^` ^t>
MODEL_PATH    = '/home/pi/lane_model.onnx'
JSON_PORT     = 9999   # ROS2 bridge connects here
VIDEO_PORT    = 9998   # viewer on laptop connects here
INPUT_W       = 320
INPUT_H       = 240
ALPHA         = 0.3
SOLID_ALPHA   = 0.4
SEP_THRESHOLD = 110.0
LANE_HISTORY  = 10
MIN_VOTES     = 6

#  ^t^` ^t^` Real-world lane width (confirmed by measurement)  ^t^` ^t^` ^t^` ^t^` ^t^` ^t^` ^t^`
LANE_WIDTH_CM = 36.7

#  ^t^` ^t^` CM calibration (PLACEHOLDERS until you run the test)  ^t^` ^t^` ^t^`
# Run Test A (outer) and Test B (inner) below, then fill in
# real numbers here. Until then error_cm == error in px
# (offset 0, scale 1)  ^`^t completely harmless default.
ERROR_OFFSET_OUTER_PX = -8.5
ERROR_OFFSET_INNER_PX = -7.5
PIXELS_PER_CM_OUTER    = 2.19
PIXELS_PER_CM_INNER    = 2.51




#  ^t^` ^t^` Colors  ^t^` ^t^` ^t^` ^t^` ^t^` ^t^` ^t^` ^t^` ^t^` ^t^` ^t^` ^t^` ^t^` ^t^` ^t^` ^t^` ^t^` ^t^` ^t^` ^t^` ^t^` ^t^` ^t^` ^t^` ^t^` ^t^` ^t^` ^t^` ^t^`>
COLOR_WHITE = (255, 255, 255)
COLOR_GREEN = (0, 255, 0)
COLOR_CYAN  = (0, 255, 255)
COLOR_BLUE  = (255, 0, 0)
COLOR_BLACK = (0, 0, 0)

mask_colors = np.array([
    [50,  50,  50],
    [0,   255, 0 ],
    [0,   255, 255],
], dtype=np.uint8)


#  ^t^` ^t^` Load model  ^t^` ^t^` ^t^` ^t^` ^t^` ^t^` ^t^` ^t^` ^t^` ^t^` ^t^` ^t^` ^t^` ^t^` ^t^` ^t^` ^t^` ^t^` ^t^` ^t^` ^t^` ^t^` ^t^` ^t^` ^t^` ^t^` ^t^` ^t^` >
print('Loading model...')
sess_options = ort.SessionOptions()
sess_options.intra_op_num_threads = 4
sess_options.inter_op_num_threads = 4


sess = ort.InferenceSession(
    MODEL_PATH,
    sess_options=sess_options,
    providers=['CPUExecutionProvider'])

input_name = sess.get_inputs()[0].name
print(f'Model loaded: {input_name}')


#  ^t^` ^t^` State  ^t^` ^t^` ^t^` ^t^` ^t^` ^t^` ^t^` ^t^` ^t^` ^t^` ^t^` ^t^` ^t^` ^t^` ^t^` ^t^` ^t^` ^t^` ^t^` ^t^` ^t^` ^t^` ^t^` ^t^` ^t^` ^t^` ^t^` ^t^` ^t^` >
prev_center    = None
prev_solid_pos = None
prev_sep_pos   = None
lane_history   = deque(maxlen=LANE_HISTORY)
width_history  = deque(maxlen=50)
current_lane   = 'unknown'

#  ^t^` ^t^` Calibration test buffer (terminal-only, no effect on
#    streaming)  ^t^` ^t^` ^t^` ^t^` ^t^` ^t^` ^t^` ^t^` ^t^` ^t^` ^t^` ^t^` ^t^` ^t^` ^t^` ^t^` ^t^` ^t^` ^t^` ^t^` ^t^` ^t^` ^t^` ^t^` ^t^` ^t^` ^t^` ^t^` ^t^` ^t^>
calib_buffer = deque(maxlen=15)


#  ^t^` ^t^` Preprocess  ^t^` ^t^` ^t^` ^t^` ^t^` ^t^` ^t^` ^t^` ^t^` ^t^` ^t^` ^t^` ^t^` ^t^` ^t^` ^t^` ^t^` ^t^` ^t^` ^t^` ^t^` ^t^` ^t^` ^t^` ^t^` ^t^` ^t^` ^t^` >
def preprocess(frame_bgr):
    frame_rgb = cv2.cvtColor(
        frame_bgr, cv2.COLOR_BGR2RGB)
    inp = cv2.resize(
        frame_rgb, (INPUT_W, INPUT_H),
        interpolation=cv2.INTER_LINEAR)
    inp = inp.astype(np.float32) / 255.0
    inp = inp.transpose(2, 0, 1)[np.newaxis]
    return inp

#  ^t^` ^t^` Geometry  ^t^` ^t^` ^t^` ^t^` ^t^` ^t^` ^t^` ^t^` ^t^` ^t^` ^t^` ^t^` ^t^` ^t^` ^t^` ^t^` ^t^` ^t^` ^t^` ^t^` ^t^` ^t^` ^t^` ^t^` ^t^` ^t^` ^t^` ^t^` ^t>
def extract_geometry(mask):
    global prev_center, prev_solid_pos
    global prev_sep_pos, current_lane

    h, w   = mask.shape
    img_cx = w / 2.0

    roi_top = int(h * 0.20)
    roi     = mask[roi_top:, :]

    solid_cols = np.where(roi == 1)[1]
    sep_cols   = np.where(roi == 2)[1]

    solid_count = len(solid_cols)
    sep_count   = len(sep_cols)

    # Track actual detection this frame
    actually_has_sep   = sep_count   > 8
    actually_has_solid = solid_count > 8

    sep_x   = float(np.mean(sep_cols)) \
               if actually_has_sep   else None
    solid_x = float(np.mean(solid_cols)) \
               if actually_has_solid else None

    # Smooth solid
    if solid_x is not None:
        if prev_solid_pos is not None:
            solid_x = SOLID_ALPHA * solid_x + \
                      (1-SOLID_ALPHA) * prev_solid_pos
        prev_solid_pos = solid_x
    elif prev_solid_pos is not None:
        solid_x        = prev_solid_pos
        prev_solid_pos = prev_solid_pos * 0.95

    # Smooth separator
    if sep_x is not None:
        if prev_sep_pos is not None:
            sep_x       = SOLID_ALPHA * sep_x + \
                          (1-SOLID_ALPHA) * prev_sep_pos
        prev_sep_pos = sep_x
    elif prev_sep_pos is not None:
        sep_x        = prev_sep_pos
        prev_sep_pos = prev_sep_pos * 0.95

    # Lane width
    if solid_x is not None and sep_x is not None:
        lw = abs(solid_x - sep_x)
        if 20 < lw < w * 0.9:
            width_history.append(lw)

    lw = float(np.median(width_history)) \
         if len(width_history) >= 5 else w * 0.25

    # Lane detection using separator position
    if actually_has_sep and sep_x is not None:
        if sep_x < SEP_THRESHOLD:
            lane_history.append('outer')
        else:
            lane_history.append('inner')

    counts = Counter(lane_history)
    if counts and len(lane_history) >= 3:
        best, n = counts.most_common(1)[0]
        if n >= MIN_VOTES:
            current_lane = best

    # Lane center using ACTUAL detection only
    # (this is already lane-aware in every branch  ^`^t unchanged)
    if actually_has_solid and actually_has_sep:
        center = (solid_x + sep_x) / 2
        conf   = 1.0
    elif actually_has_solid:
        if current_lane == 'outer':
            center = solid_x - lw / 2
        elif current_lane == 'inner':
            center = solid_x - lw / 2
        else:
            center = solid_x
        conf = 0.5
    elif actually_has_sep:
        if current_lane == 'outer':
            center = sep_x + lw / 2
        elif current_lane == 'inner':
            center = sep_x - lw / 2
        else:
            center = sep_x
        conf = 0.4
    elif prev_center is not None:
        center = prev_center
        conf   = 0.2
    else:
        center = img_cx
        conf   = 0.0

    if prev_center is None:
        prev_center = center
    center      = ALPHA * center + \
                  (1-ALPHA) * prev_center
    prev_center = center
    error       = center - img_cx
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

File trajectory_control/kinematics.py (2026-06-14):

"""
Differential drive kinematic model.

This is the same math running on the STM32 for odometry, just here in
Python so we can simulate it quickly without re-flashing hardware every
time we change a parameter.

Two directions:
- forward kinematics: wheel speeds (v_left, v_right) -> robot motion (v, omega)
  Used for ODOMETRY (estimating where the robot is from wheel motion).
- inverse kinematics: desired robot motion (v, omega) -> wheel speeds (v_left, v_right)
  Used for CONTROL (converting a planner's desired motion into wheel commands).
"""

import math


class DiffDriveKinematics:
    def __init__(self, wheel_radius, track_width):
        self.r = wheel_radius   # meters, calibrated value
        self.L = track_width    # meters, distance between left/right wheel centers

    def inverse(self, v, omega):
        """
        Desired robot motion -> required wheel speeds.

        v     : desired linear velocity of the robot center (m/s)
        omega : desired angular velocity of the robot (rad/s), positive = turning left (CCW)

        Returns (v_left, v_right) in m/s -- the speed each side's wheels
        need to spin at to produce that motion.
        """
        v_left = v - (omega * self.L) / 2.0
        v_right = v + (omega * self.L) / 2.0
        return v_left, v_right

    def forward(self, v_left, v_right):
        """
        Wheel speeds -> resulting robot motion.

        v_left, v_right : current speed of left/right side wheels (m/s)

        Returns (v, omega) -- the robot's resulting linear and angular velocity.
        This is the direction used for odometry.
        """
        v = (v_left + v_right) / 2.0
        omega = (v_right - v_left) / self.L
        return v, omega

    def mps_to_rpm(self, speed_mps):
        """Convert a wheel's linear speed (m/s) to RPM, for sending to your PID targets."""
        wheel_circumference = 2 * math.pi * self.r
        rps = speed_mps / wheel_circumference  # revolutions per second
        return rps * 60.0

    def rpm_to_mps(self, rpm):
        """Convert RPM (from encoder feedback) to linear wheel speed (m/s)."""
        wheel_circumference = 2 * math.pi * self.r
        rps = rpm / 60.0
        return rps * wheel_circumference

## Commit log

2026-01-18 v3 training — rate-based steering + positive reward
2026-05-15 create chassis and pcb folder structure
2026-06-02 stm32 pid motor control with encoder feedback
2026-06-03 add uart protocol docs
2026-06-04 motor test with feedback modes
2026-06-04 keyboard-controlled motor test
2026-06-09 differential drive kinematics
2026-06-10 uart bridge for sending targets to stm32
2026-06-13 trajectory controller v11 — pid lane keeping + lane change state machine
2026-06-18 camera receiver node for parking pipeline
2026-06-19 ros2 lane_bridge package — tcp to ros2 topics
2026-06-23 yolo node for detecting parking slots
2026-06-25 ros2 lidar_bridge — tcp scan to /scan topic
2026-06-25 lane analyzer — processes unet output for parking geometry
2026-06-26 acc controller node — zone detection and speed commands
2026-06-27 parking slot scoring and selection
2026-06-27 pi-side motor server — receives speed over tcp, sends to stm32
2026-06-29 decision manager — coordinates parking state machine
2026-07-02 wheel mixer — converts velocity commands to motor speeds
2026-07-17 Adding Car design CAD files
    [65mm tire.SLDPRT, DC motor Mount.SLDPRT, DC-Motor.SLDPRT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]
